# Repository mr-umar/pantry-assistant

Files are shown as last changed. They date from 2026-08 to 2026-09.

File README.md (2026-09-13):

# Autonomous pantry assistant for low-Vision users

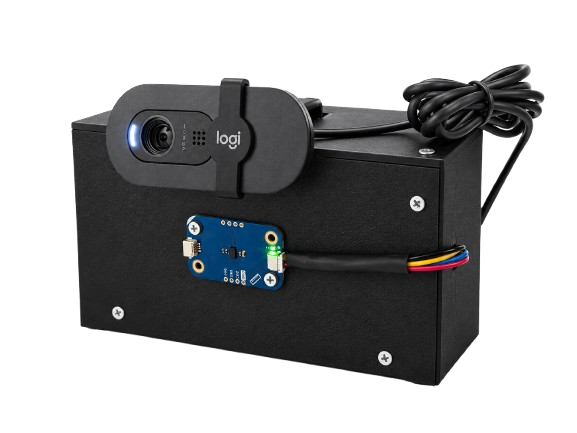
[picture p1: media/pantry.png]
Pantry Assistant


This is an automated system to recognize pantry items. It runs on the **Arduino UNO Q** dual-brain architecture. It uses a Time-of-Flight hardware sensor on the microcontroller to measure distance, combined with Edge Impulse AI and RapidOCR text reading on Debian Linux.

Developed for **[Hackestiu 2026](https://catedrachip.upc.edu/es/hackestiu_2026_democratiza_inteligencia_artificial/)** (Càtedra CHIP UPC & Qualcomm).

---

## Authors

* **Lluis Vidal** ([@Lluisvidal89](https://github.com/Lluisvidal89))
* **Umar Mohammad** ([@mr-umar](https://github.com/mr-umar))

---

## Quick Start (One-Liner Installation)

Run this single command in your Arduino UNO Q terminal. It will clone the repository, install all dependencies, and flash the STM32 microcontroller:

```bash
git clone https://github.com/mr-umar/pantry-assistant.git && cd pantry-assistant && chmod +x install.sh run.sh src/model.eim && ./install.sh

```

Once installed, start the system:

```bash
./run.sh

```

Open a web browser on any device connected to the same local network:

```text
http://<ARDUINO_UNO_Q_IP>:5000

```

---

## Demo

Click to watch:

Demo Hackestiu (https://www.youtube.com/watch?v=OMCTbtRUUI4)

## System Architecture

This assistant helps people with low vision identify grocery packages (like canned chickpeas or tomato sauce). It works entirely on the device without needing the internet. This guarantees zero delay and keeps your data completely private.

```text
+--------------------------------------------------------------------------+
|                            Arduino UNO Q                                 |
|                                                                          |
|  +---------------------------+       +--------------------------------+  |
|  |     STM32U585 (MCU)       |       |  Qualcomm Dragonwing QRB2210   |  |
|  |                           |       |         (Debian Linux)         |  |
|  |  - Modulino Distance      |       |                                |  |
|  |                           |  RPC  |  - UNIX Socket Bridge Client   |  |
|  |  - Arduino_RouterBridge   | ----> |  - Stability Filter (25-50 cm) |  |
|  |    service provider       |       |  - Edge Impulse Model (.eim)   |  |
|  +---------------------------+       |  - Fallback RapidOCR Engine    |  |
|                                      |  - Flask Telemetry Streamer    |  |
|                                      +--------------------------------+  |
+--------------------------------------------------------------------------+

```

### 1. Dual-Core Hardware Integration

* **Microcontroller (STM32U585)**: It constantly checks an **Arduino Modulino Distance** sensor connected to the physical Qwiic port (`Wire1` / I2C4 bus). It sets up an RPC method (`get_distance`) using the official `Arduino_RouterBridge` library.
* **Microprocessor (Qualcomm Dragonwing)**: A light Python client asks for measurements directly through `/var/run/arduino-router.sock` using standard MessagePack-RPC, avoiding heavy graphical interfaces.

### 2. Distance & Stability Filter

To avoid blurry pictures and save computer power, the AI only works when you hold a product steady between **25 and 50 cm** (250 mm to 500 mm) from the sensor for a few seconds.

### 3. AI Pipeline

* **Primary Stage (Edge Impulse)**: It checks high-quality camera images using an Edge Impulse model (`src/model.eim`) saved on the device. This model finds the product and identifies it.
* **Fallback Stage (RapidOCR)**: If the system cannot find the product, or if it is not very sure (less than 80% confidence), it sends the image to **RapidOCR**. This tool reads the text and brand names on the packaging.

### Edge Impulse Machine Learning Pipeline
- **Edge Impulse Project:** [Pantry Detector](https://studio.edgeimpulse.com/studio/1106136)
- **Model Architecture:** YOLO-Pro (Float32 unoptimized for ARM Cortex-A)
- **Dataset:** 220+ images [automatically labeled with Gemini 3.5 Flash Lite](/Labelling/)
- **Deployment:** Compiled standalone `.eim` binary targeting Arduino UNO Q

---

## Hardware Bill of Materials

* **Arduino UNO Q** (2GB or 4GB)*
* **Arduino Modulino Distance** (ABX00102)
* **10cm Qwiic cable**
* **Any USB Webcam** (1080p compatible)**
* **USB Type-C Power Supply** - **USB-C Hub for power and camera**

* The 2GB version of the UNO Q should be enough for this project.
 
**We used the provided Logitech Brio 105 with manual focus set for our needs. You can adjust the focus of your webcam by turning the lens ring, as shown in the following image:

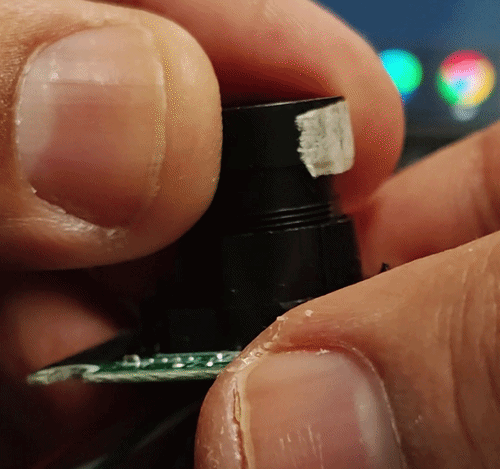
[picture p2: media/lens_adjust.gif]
Webcam Focus


Logitech adds glue to the ring, but you can remove it easily with isopropyl alcohol :) 

---

## Manual Step-by-Step Setup

If you prefer to run each step yourself instead of using `install.sh`:

### 1. Install Debian packages

```bash
sudo apt update
sudo apt install -y python3-pip python3-opencv python3-pyaudio portaudio19-dev python3-msgpack

```

### 2. Install Python dependencies

*(The following command installs them for the whole system. We recommend using a virtual environment instead).*

```bash
pip install -r src/requirements.txt --break-system-packages

```

### 3. Flash the STM32 firmware

```bash
arduino-cli lib update-index
arduino-cli lib install "Arduino_Modulino" "Arduino_RouterBridge"
cd firmware
arduino-cli compile --fqbn arduino:zephyr:unoq -u .
cd ..

```

### 4. Set permissions and run

```bash
chmod +x src/model.eim run.sh
./run.sh

```

### 5. (Optional) Remote Access with Tailscale

If you want to connect to the assistant from a device outside your local network:

```bash
curl -fsSL https://tailscale.com/install.sh | sh
sudo tailscale up

```

---

## 3D Case

Check the 3D folder for the STL files if you need them.

---

## AI Assistance Disclaimer
Parts of the code and documentation in this repository were generated or refined with the assistance of AI tools. All AI-generated logic has been reviewed, tested, and modified by the authors to ensure it meets the specific hardware and software requirements of this project.

## License

Developed for the **Hackestiu 2026** competition. Open source and available under the MIT License.

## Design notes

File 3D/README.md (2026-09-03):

# 3D Printing Instructions

## Print Setup

| Parameter | Recommended Value |
| :--- | :--- |
| **Material** | PLA / PETG |
| **Layer Height** | 0.16 mm – 0.24 mm |
| **Walls** | > 4 perimeters |
| **Infill** | 15% – 20% |
| **Supports** | Tree Supports (enabled for `HUB_Base.stl`) |

---

## Hardware Required

* **Screws/Bolts:** M3 x 10 mm (1 cm)

---

## Part-Specific Notes

* **`HUB_Base.stl`**: Make sure to **enable tree supports** before slicing to ensure clean overhangs and easy removal.

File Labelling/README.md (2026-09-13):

# Dataset auto-labelling

Automates bounding box annotations for pantry items using Google Gemini Flash Lite and exports directly into Edge Impulse format (`bounding_boxes.labels`).

## Requirements

Install dependencies:

```bash
pip install google-genai pillow pillow-heif
```

Set your Gemini API key:

```bash
# Linux / macOS
export GEMINI_API_KEY="your_api_key"

# Windows (PowerShell)
$env:GEMINI_API_KEY="your_api_key"
```

## Usage

1. Place source images (`.heic`, `.jpg`, `.png`) into `./dataset_fotos/`.
2. Run the script:
   ```bash
   python labelling.py
   ```
3. Upload the resulting `./output_edge_impulse/` directory to Edge Impulse Studio.

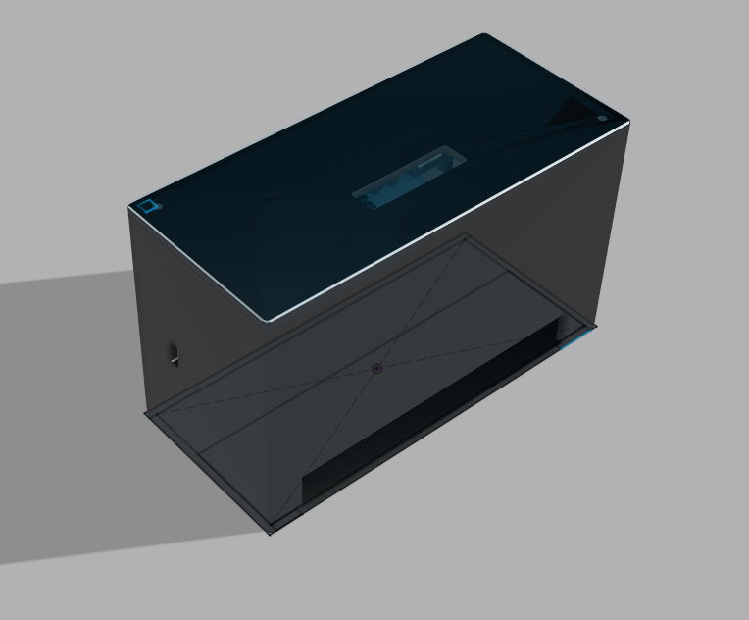
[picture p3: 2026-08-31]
3D/Box.png

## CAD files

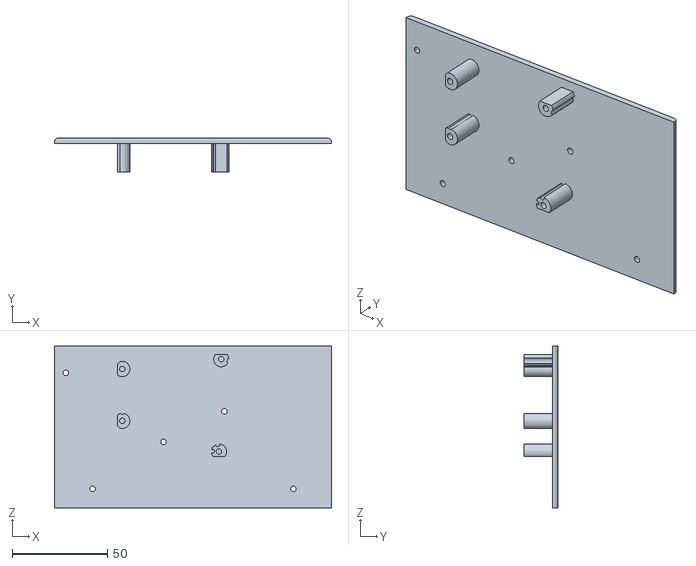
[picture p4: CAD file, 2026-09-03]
3D/Arduino_Base.stl
145.6 x 17.8 x 85.0

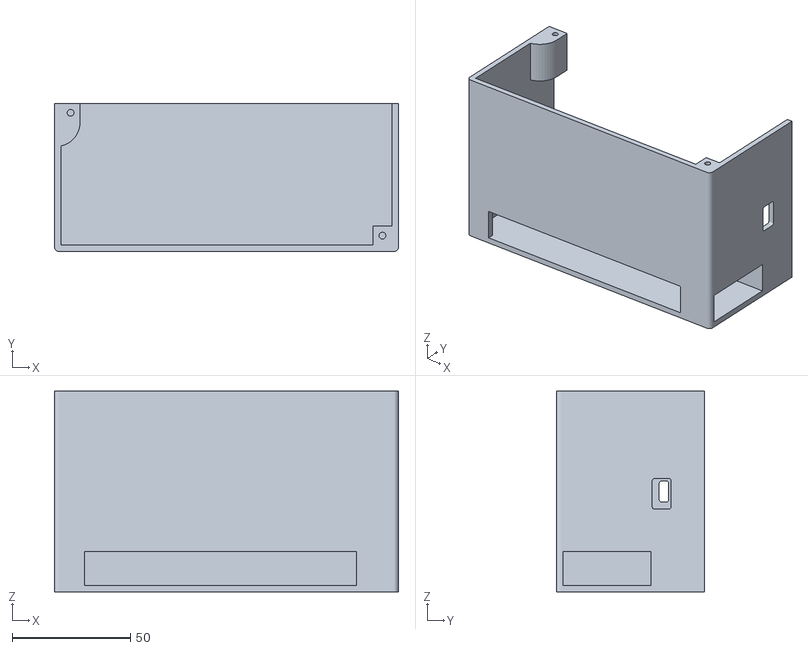
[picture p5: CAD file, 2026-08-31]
3D/HUB_Base.stl
145.6 x 62.8 x 85.0

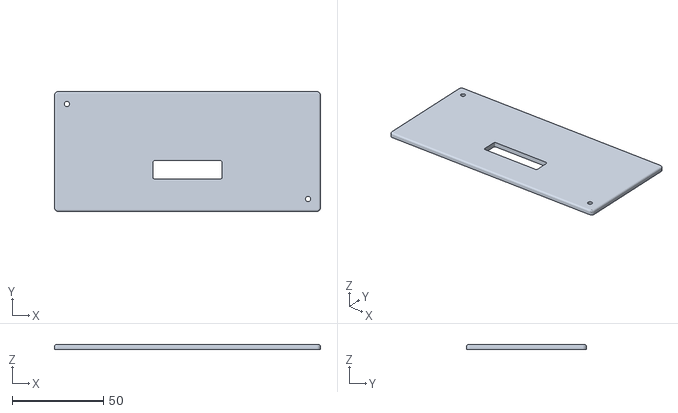
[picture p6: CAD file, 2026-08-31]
3D/Camera_Base.stl
145.6 x 65.6 x 2.80

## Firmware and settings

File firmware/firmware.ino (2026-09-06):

#include <Wire.h>
#include <Arduino_Modulino.h>
#include <Arduino_RouterBridge.h>

ModulinoDistance distanceSensor;
volatile int current_distance = -1;

String getDistanceHandler(String args) {
  return String(current_distance);
}

void setup() {
  Bridge.begin();

  // Initialize Qwiic bus (Wire1 on UNO Q)
  Wire1.begin();
  delay(100);

  // Bind Modulino library to Wire1
  Modulino.begin(Wire1);
  delay(200);

  // Start Time-of-Flight sensor
  distanceSensor.begin();
  delay(100);

  // Register MessagePack-RPC method
  Bridge.provide("get_distance", getDistanceHandler);
}

void loop() {
  Bridge.update();

  // Poll sensor continuously on the STM32 loop
  if (distanceSensor.available()) {
    int val = distanceSensor.get();
    if (val > 0) {
      current_distance = val;
    }
  }

  delay(100);
}

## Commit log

2026-08-31 3D Prints
    [ArduinoBaseWall.stl, Body.stl, Cover.stl]
2026-08-31 Readme for prints
2026-09-03 Refactor code structure for improved readability and maintainability
    [ArduinoBaseWall.stl, Arduino_Base.stl, Camera_Base.stl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]
2026-09-06 feat: implement distance-gated AI pipeline with Flask backend and update stability range to 25-50cm
2026-09-06 feat: implement camera-based detection service with Edge Impulse model and OCR fallback
2026-09-09 feat: add Gemini-powered auto-labelling tool and update project authorship credits
2026-09-09 docs: update README with refined hardware bill of materials and webcam focus adjustment guide
